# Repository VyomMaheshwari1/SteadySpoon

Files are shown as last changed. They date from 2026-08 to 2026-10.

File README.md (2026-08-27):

SteadySpoon

SteadySpoon is a prototype active-stabilization utensil that I'm building to experiment with reducing tremor-like hand motion.

The current setup uses an STM32G431 and an MPU6050. So far I've implemented I2C sensor communication, gyro calibration, tilt estimation, accelerometer/gyro fusion using a complementary filter, and PWM setup for the servos.

Right now I'm working on getting the first physical servo axis running.

\## Hardware

\- STM32 NUCLEO-G431KB

\- MPU6050 IMUs

\- KST DS215MG servos

\- External servo power supply

\## Current progress

\- STM32 + MPU6050 communication working

\- Real accelerometer and gyro readings working

\- Gyro bias calibration implemented

\- Complementary-filter angle estimation working

\- Servo PWM configured

\- Physical servo testing next

This is still a work in progress. CAD, test data, and stabilization results will be added as the prototype develops.

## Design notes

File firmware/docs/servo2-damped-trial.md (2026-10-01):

# Servo 2 damped controller trial

This revision is an unvalidated bench controller. It starts with Servo 2 held at 1500 us and Servo 1 centered. Physical stabilization performance has not been demonstrated. Do not mistake hold-center mode for active stabilization.

## Changes

- Correct gyro-rate projection to match the bounded accelerometer tilt definitions, including inverted sensor mounting.
- Retry MPU startup with bounded, open-drain I2C bus recovery and retained diagnostics.
- Use angle gain 2 us/degree, rate damping 0.08 us/(degree/s), and a 30 ms rate filter. Damping is limited to +/-20 us.
- Use integral gain 1 us/(degree*s), limited to 10 us/s and +/-150 us, with anti-windup.
- Limit commands to 1150–1850 us and nominal changes to 6 us per 10 ms control tick.
- Configure Servo 2 TIM3 for approximately 333 Hz PWM with 1 us resolution, for the KST DS215MG V8.0. Servo 1 timing is unchanged.

## Defaults and fault behavior

`servo2_hold_center_test` defaults to 1. Enabling feedback requires an explicit, supervised bench action. Automatic actuator testing is disabled.

`servo2_control_fault` latches until reset:

| Code | Trigger |
|---|---|
| 1 | Invalid, stale, nonfinite, or singular-coordinate sensor data |
| 2 | Active control interval outside the permitted timing window |
| 3 | Any carriage gyro axis reaches 450 degrees/second |
| 4 | Four rate reversals exceeding +/-100 degrees/second within 500 ms |

A fault freezes the last PWM command. It does **not** disconnect motor power. The oscillation guard can also trip on vigorous imposed motion; it is not a tremor classifier. Reset returns to hold-center mode.

Keep external servo power off when flashing. Refresh CubeMonitor variable addresses from the exact newly flashed ELF; rebuilding can move globals. Never use a stale zero-valued graph as evidence of stabilization. Include fault, inhibit, hold-center and sensor-health fields in subsequent recordings.

## Validation

ARM firmware build passed. Eleven isolated host tests exercise the actual controller functions: startup hold, command slew/integral limits, damping direction and decay, clipping/reversal latches, timing, stale data, anti-windup, timer wrap, duplicate samples and nonfinite input. Run `python firmware/tests/test_servo2_controller.py` with a host GCC compiler installed (`CC` can select it).

Replay of a prior unstable recording triggered the reversal guard and held the output. Replay verifies response to recorded inputs, not new closed-loop physical behavior. Hardware validation is still required. Known build warnings concern unused Servo 1 stabilization and the legacy automatic-response helper.

Reference: [KST DS215MG V8.0 specification](https://www.kst-servo-shop.de/media/9b/d5/38/1751020226/KST_0821_DS215MG_V8_Datenblatt_04_2025_de.pdf).

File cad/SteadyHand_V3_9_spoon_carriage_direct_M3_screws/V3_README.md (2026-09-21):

# SteadyHand V3.9 with direct screws in the spoon carriage

V3.9 keeps the corrected left-side servo wire opening and changes the spoon
carriage connection so it no longer requires heat-set inserts. The two former
4.6 mm insert pockets are now 2.6 mm pilot holes for ordinary M3 screws.

The handle correction was developed after inspecting a physical-fit
photo. The black rubber strain-relief was hitting the mounting wall before the
servo case could seat. The user confirmed that this interference is on the
left, so the lower-left mounting point is replaced by the wire-boot opening.
The servo lead is permanently attached, so clearance behind the servo was not
enough by itself: the lead also needs an open route through the mounting plate.

## V3.9 spoon-carriage change

- The red pitch-horn adapter retains 3.4 mm pass-through clearance holes.
- The yellow moving spoon carriage now has two 2.6 mm pilot holes.
- Use two M3 x 10 mm machine screws through the adapter. They form threads
  directly in the printed carriage bosses; no inserts or nuts are required.
- Do not drill the 2.6 mm carriage holes larger and do not overtighten them.

## Retained handle changes

- An 18 x 10 mm opening now occupies the lower-left servo mounting point.
- That opening overlaps the servo body opening and reaches the plate's side
  edge, allowing the black rubber boot and cable to enter without bending.
- The roll servo is fastened using the other three DS215 mounting holes. A 6 mm
  protected zone around each retained screw has been checked against the slot.
- Handle height is 34 mm: 2 mm more above and 2 mm more below the centerline.
- A dedicated 12 x 12 x 12 mm service envelope now clears the roll-servo rubber
  boot and the cable's first bend, not only the metal case.
- A small local side blister preserves wall thickness around that cable pocket.
- Front harness opening increased from 18 x 6 mm to 24 x 10 mm.
- Rear cable opening increased from 16 x 10 mm to 20 x 12 mm.
- Pitch-servo wire passage increased from 10 x 6 mm to 14 x 9 mm.

## Printable parts

1. `V3_9_DS215_fit_test_coupon.stl` - optional quick body/hole-pattern check.
2. `V3_9_handle_tray.stl` - includes the three-hole servo mount and left wire opening,
   Nucleo rails/zip-tie slots, and four handle-IMU standoffs.
3. `V3_9_handle_lid.stl` - flat four-screw lid with no tray interference.
4. `V3_9_integrated_outer_frame.stl` - roll yoke and pitch-servo bracket are one
   printed solid; there is no unexplained bracket-to-frame joint.
5. `V3_9_integrated_moving_carriage.stl` - pitch platform and spoon socket are one
   printed solid, now with two direct-screw M3 pilot holes.
6. `V3_9_pitch_horn_adapter.stl` - removable bridge from the purchased pitch
   horn to the moving carriage. This makes the center horn screw accessible.

## Verified interfaces

- KST DS215MG V8: 23 x 12 x 27.5 mm case, 32 x 12 mm ear envelope,
  four 2.5 mm holes on a 28 x 7 mm pattern, 25T/5 mm spline.
- KST-5034 one-arm horn: 28.4 mm overall, 7.5 mm wide, 1.8 mm arm,
  four 1.6 mm holes at 10, 13.5, 17, and 20.5 mm from the spline axis.
  The design uses the 10 and 17 mm holes at both powered joints.
- The round-looking 5 mm output is actually a 25-tooth spline. V3.9 shows
  visible conceptual teeth and the center retaining screw so the joint is not
  mistaken for a smooth pin. The tooth shape is reference-only because KST
  publishes 25T/5 mm but not the manufacturing tooth profile.
- Adafruit MPU6050 #3886: 25.4 x 17.78 mm nominal PCB outline in the Eagle
  source; four 2.5 mm holes on a 20.32 x 12.70 mm pattern.
- Neutral-position solid interference: zero for electronics, both complete
  servo references (including wire boots), the enlarged roll-wire bend
  envelope, frame, carriage, handle, and closed lid.
- Checked travel: pitch +/-50 degrees and roll +/-45 degrees.

## Required purchased hardware

- 2 x KST-5034 reinforced red plastic horn, 25T-5.
- 2 x horn-center screws supplied with the DS215 servos.
- 4 x M2 x 6-8 mm thread-forming screws for the horn-to-print connections.
- 2 x M3 x 10 mm machine screws for the pitch-adapter-to-spoon-carriage joint.
- 1 x M3 heat-set insert and one M3 pivot screw/washer for the passive pivot.

The red `REFERENCE_KST_5034...` files are purchased-part references only. Do
not print a plastic spline substitute. Print the DS215 coupon first, then
dry-fit both actual horns before printing or assembling the full mechanism.

## What attaches to what

The horn does **not** grip a smooth printed round shaft.

1. The horn's toothed center presses onto the servo's metal 25T/5 mm spline.
   The matching teeth transmit torque.
2. The small screw supplied with the servo goes through the horn center and
   threads into the servo shaft. It prevents the horn sliding off.
3. Two M2 screws through the horn's 10 and 17 mm arm holes connect it to the
   printed orange roll frame or the red pitch adapter.
4. The pitch adapter bolts to the yellow moving carriage with two M3 screws.
5. The round yellow feature on the opposite side is only the passive support
   pivot. It does not receive a servo horn and does not drive the carriage.

## Pitch-joint assembly order

1. Bolt the pitch servo to the outer frame.
2. Fasten the KST-5034 horn to `V3_9_pitch_horn_adapter` using the horn's 10 and
   17 mm holes and the adapter's two 2.2 mm holes.
3. Push the horn onto the yellow 25T servo spline and install KST's center screw
   through the adapter's large center access hole.
4. Place the moving carriage in the frame. Pass two M3 x 10 mm screws through
   the adapter's 3.4 mm holes and slowly drive them into the carriage's 2.6 mm
   pilot holes. Stop when snug; the printed plastic supplies the threads.
5. Install the M3 passive-pivot screw and washer from the left frame cheek.

For the roll joint, fasten the horn to the rear of the orange frame through its
10 and 17 mm holes, push it onto the roll-servo spline, then install the KST
center screw through the large center access opening.

## Roll-servo installation through the corrected mount

1. Put the black rubber strain-relief and attached lead into the 18 x 10 mm
   opening that replaces the lower-left screw position.
2. Slide the servo case into the rectangular opening while keeping the lead in
   the notch; do not clamp the wire under a mounting ear.
3. Install screws through the three remaining servo-ear mounting holes.
4. Route the lead through the internal bend pocket toward the controller.

If the corrected V3.8 handle and mechanism parts are already printed, keep
them. For this screw change, reprint only `V3_9_integrated_moving_carriage.stl`;
the existing V3.8 pitch-horn adapter remains compatible.

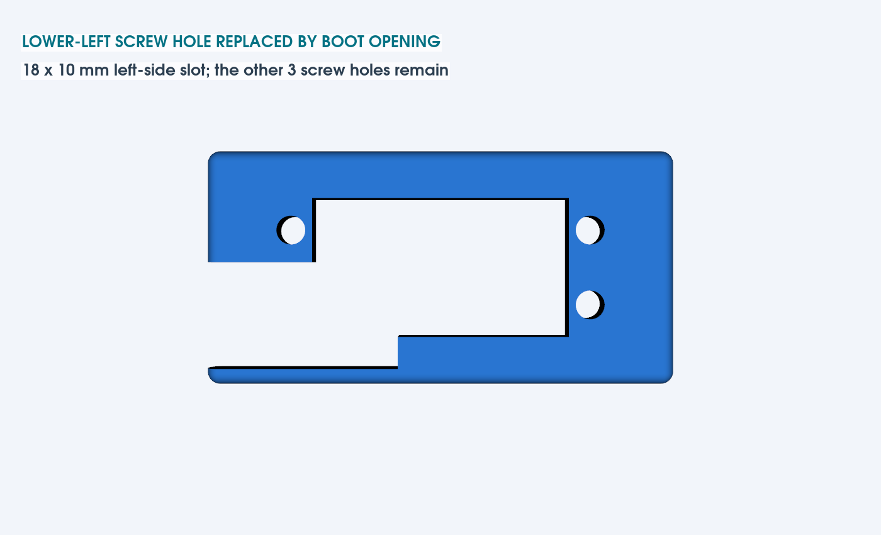
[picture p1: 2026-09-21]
cad/SteadyHand_V3_9_spoon_carriage_direct_M3_screws/PREVIEWS/V3_9_left_mount_replaced_by_wire_opening.png

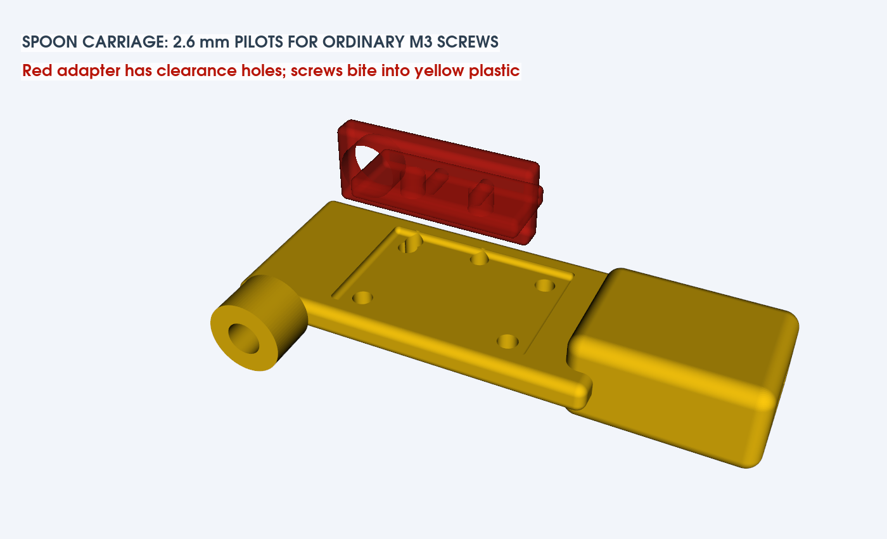
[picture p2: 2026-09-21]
cad/SteadyHand_V3_9_spoon_carriage_direct_M3_screws/PREVIEWS/V3_9_spoon_carriage_direct_M3_screws.png

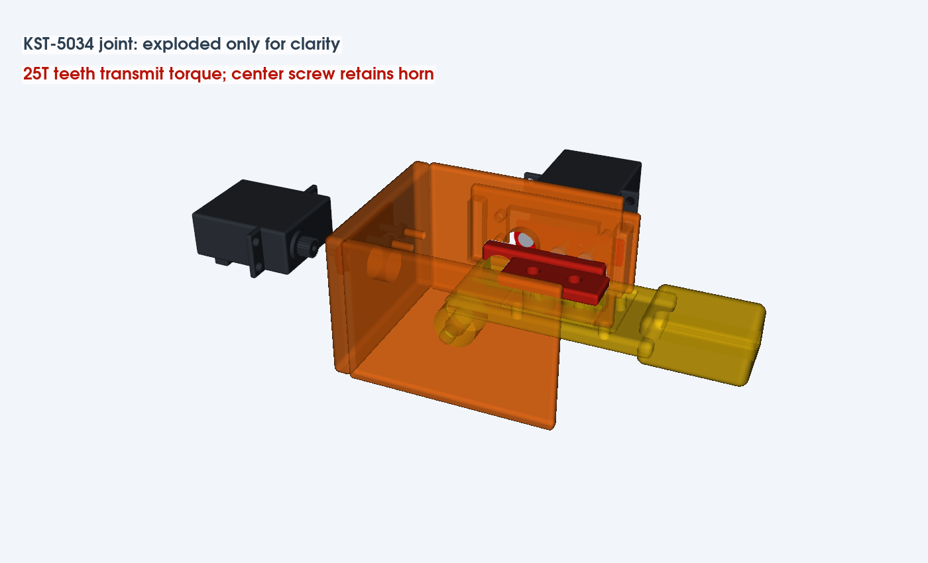
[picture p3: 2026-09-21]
cad/SteadyHand_V3_9_spoon_carriage_direct_M3_screws/PREVIEWS/V3_9_KST5034_horn_exploded.png

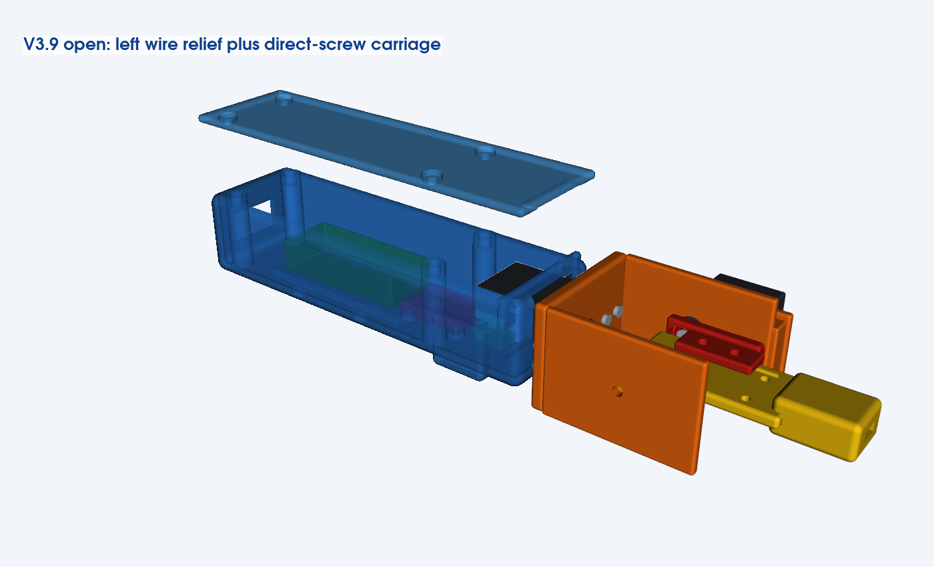
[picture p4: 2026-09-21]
cad/SteadyHand_V3_9_spoon_carriage_direct_M3_screws/PREVIEWS/V3_9_open_packaging.png

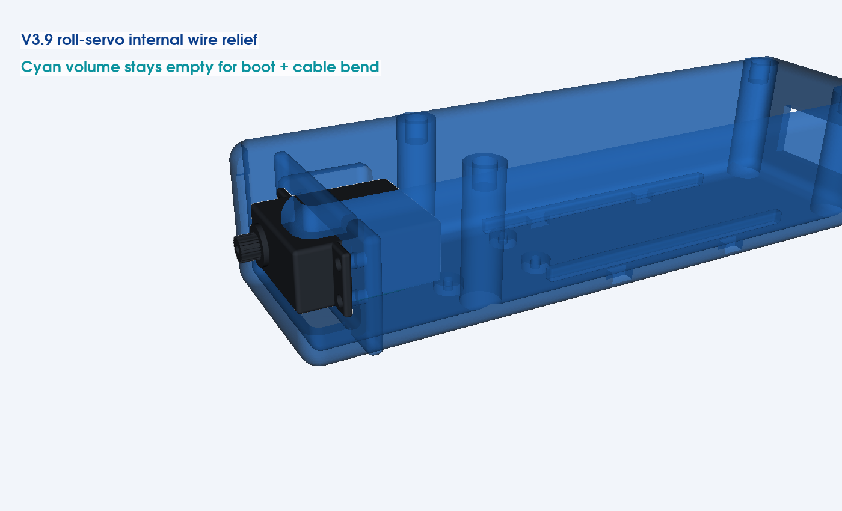
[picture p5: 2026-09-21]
cad/SteadyHand_V3_9_spoon_carriage_direct_M3_screws/PREVIEWS/V3_9_roll_servo_wire_clearance.png

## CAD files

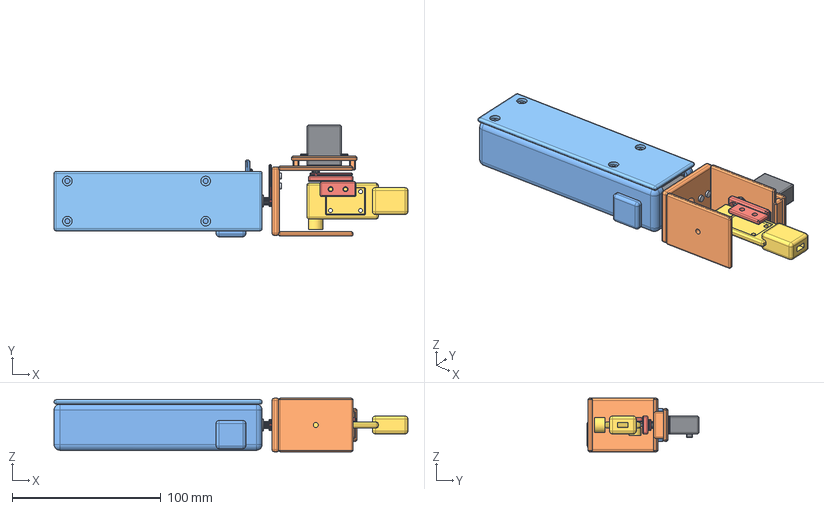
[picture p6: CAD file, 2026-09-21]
cad/SteadyHand_V3_9_spoon_carriage_direct_M3_screws/STEP_CAD/SteadyHand_V3_9_packaging_assembly.step
238.0 x 75.0 x 36.0 mm
handle_tray
handle_lid
integrated_outer_frame
integrated_moving_carriage
pitch_horn_adapter
DS215_roll_reference
DS215_pitch_reference
KST_5034_roll_horn
KST_5034_pitch_horn
roll_horn_fasteners
pitch_horn_fasteners
roll_servo_wire_service_envelope
NUCLEO_clearance_envelope
handle_IMU_envelope

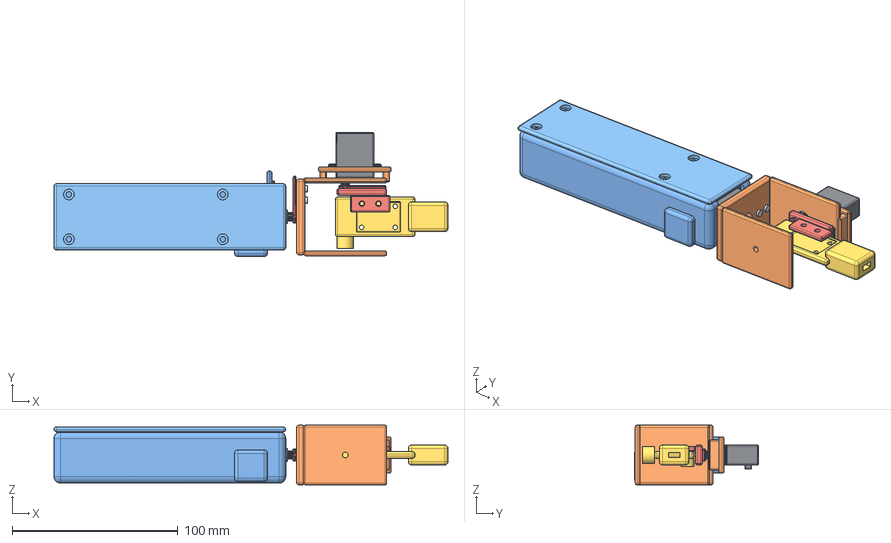
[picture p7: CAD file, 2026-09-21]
cad/SteadyHand_V3_9_spoon_carriage_direct_M3_screws/STEP_CAD/SteadyHand_V3_9_mechanical_audit_assembly.step
238.0 x 75.0 x 36.0 mm
handle_tray
handle_lid
integrated_outer_frame
integrated_moving_carriage
pitch_horn_adapter
DS215_roll_reference
DS215_pitch_reference
KST_5034_roll_horn
KST_5034_pitch_horn
roll_horn_fasteners
pitch_horn_fasteners
roll_servo_wire_service_envelope

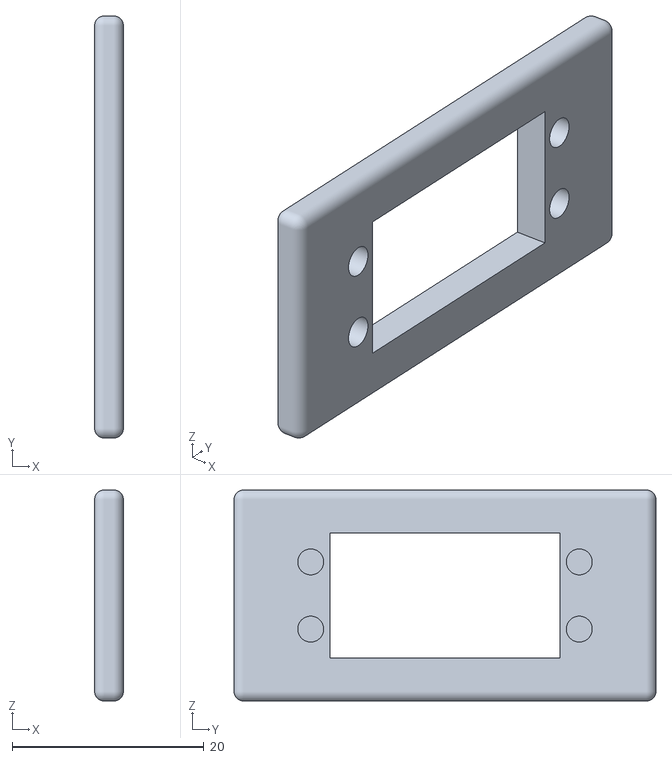
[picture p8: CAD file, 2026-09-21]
cad/SteadyHand_V3_9_spoon_carriage_direct_M3_screws/FULL_PRINT_SET_STL/V3_9_DS215_fit_test_coupon.stl
3.00 x 44.0 x 22.0

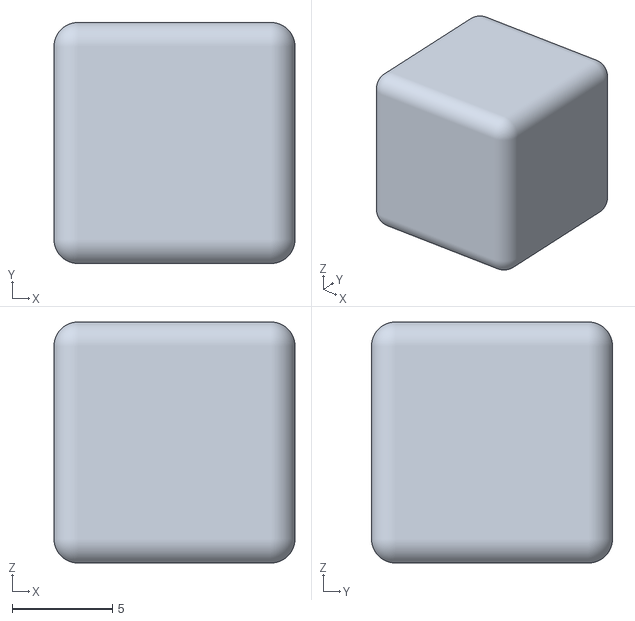
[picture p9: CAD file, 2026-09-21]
cad/SteadyHand_V3_9_spoon_carriage_direct_M3_screws/REFERENCE_DO_NOT_PRINT/REFERENCE_roll_servo_wire_service_envelope.stl
12.0 x 12.0 x 12.0

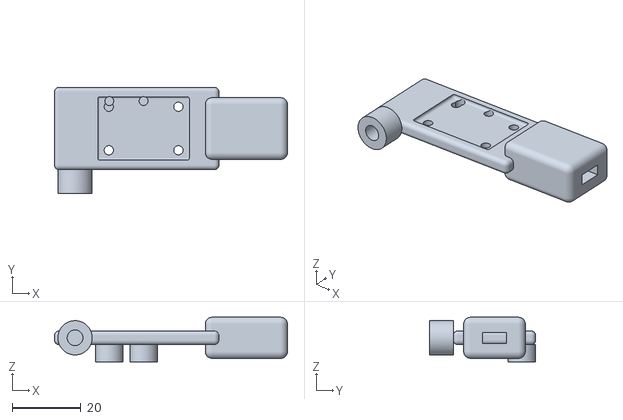
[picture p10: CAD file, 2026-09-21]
cad/SteadyHand_V3_9_spoon_carriage_direct_M3_screws/REPRINT_ONLY_THIS/V3_9_integrated_moving_carriage.stl
68.0 x 31.0 x 13.0

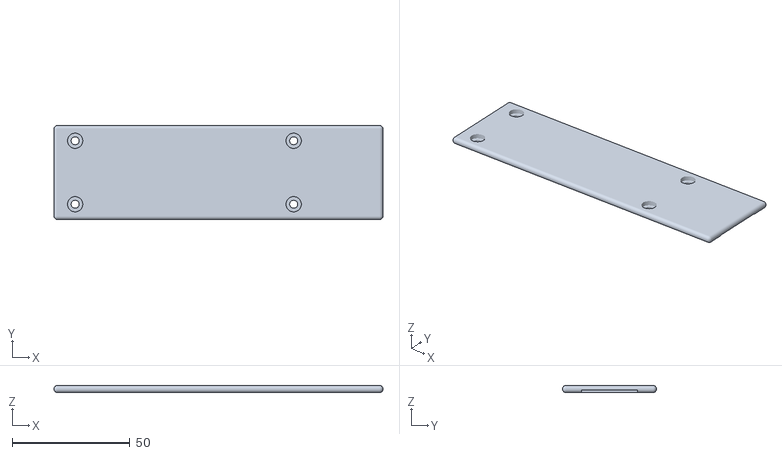
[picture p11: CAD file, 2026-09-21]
cad/SteadyHand_V3_9_spoon_carriage_direct_M3_screws/FULL_PRINT_SET_STL/V3_9_handle_lid.stl
140.0 x 40.0 x 3.00

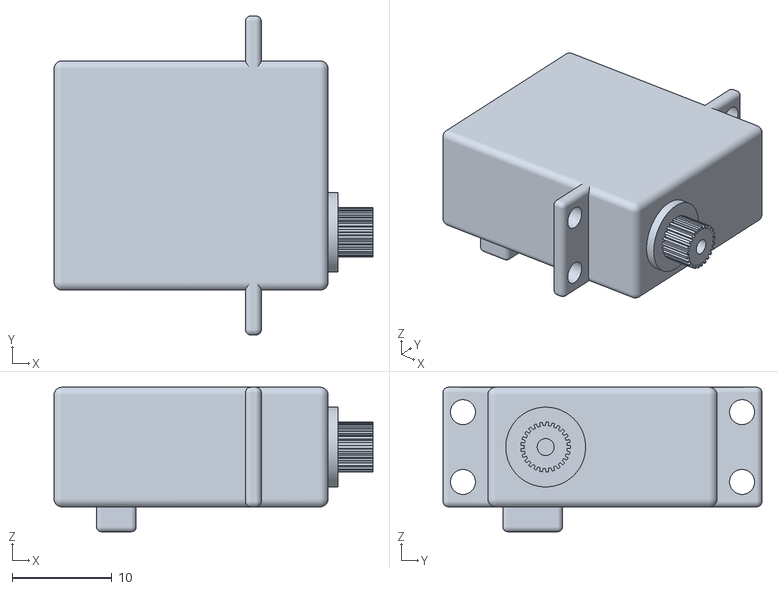
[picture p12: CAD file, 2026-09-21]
cad/SteadyHand_V3_9_spoon_carriage_direct_M3_screws/REFERENCE_DO_NOT_PRINT/REFERENCE_installed_roll_servo.stl
32.0 x 32.0 x 14.5

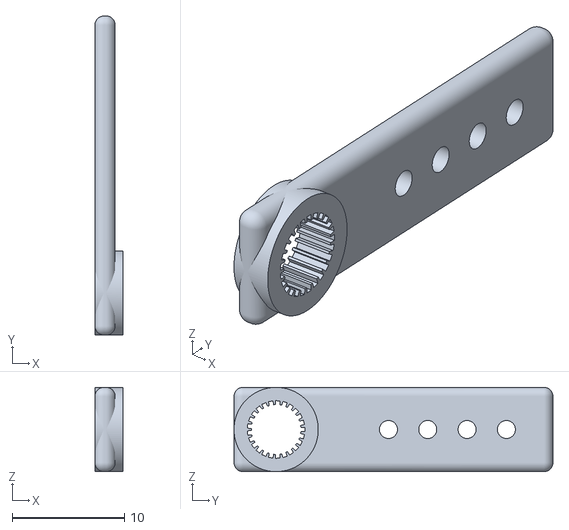
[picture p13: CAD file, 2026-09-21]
cad/SteadyHand_V3_9_spoon_carriage_direct_M3_screws/REFERENCE_DO_NOT_PRINT/REFERENCE_installed_roll_KST_5034_horn.stl
2.50 x 28.4 x 7.50

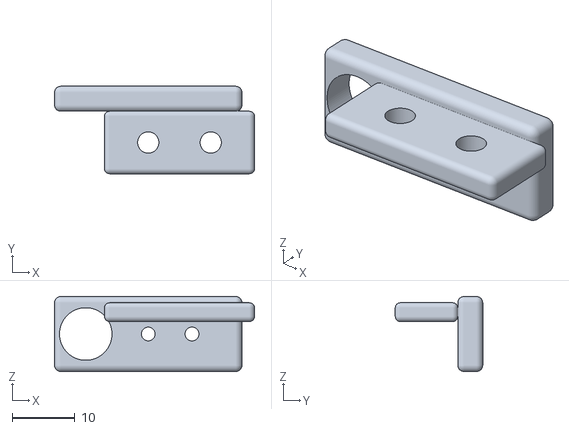
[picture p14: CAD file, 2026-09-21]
cad/SteadyHand_V3_9_spoon_carriage_direct_M3_screws/FULL_PRINT_SET_STL/V3_9_pitch_horn_adapter.stl
32.0 x 14.0 x 12.0

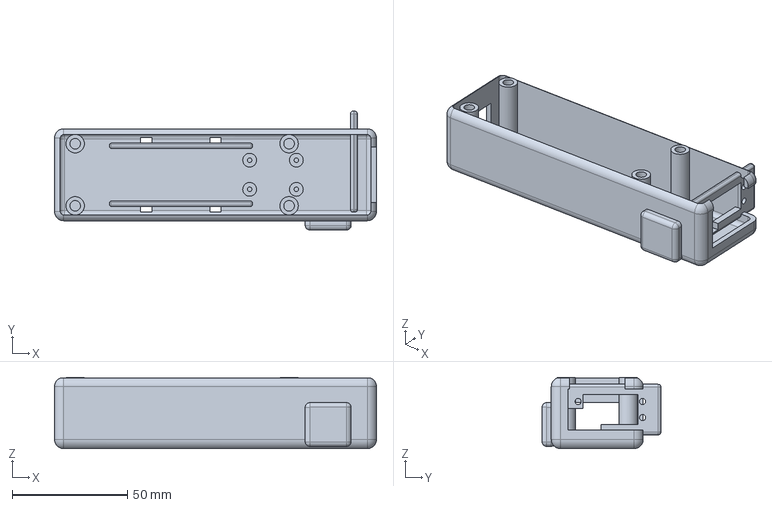
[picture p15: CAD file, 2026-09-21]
cad/SteadyHand_V3_9_spoon_carriage_direct_M3_screws/STEP_CAD/V3_9_handle_tray.step
140.0 x 51.7 x 31.0 mm

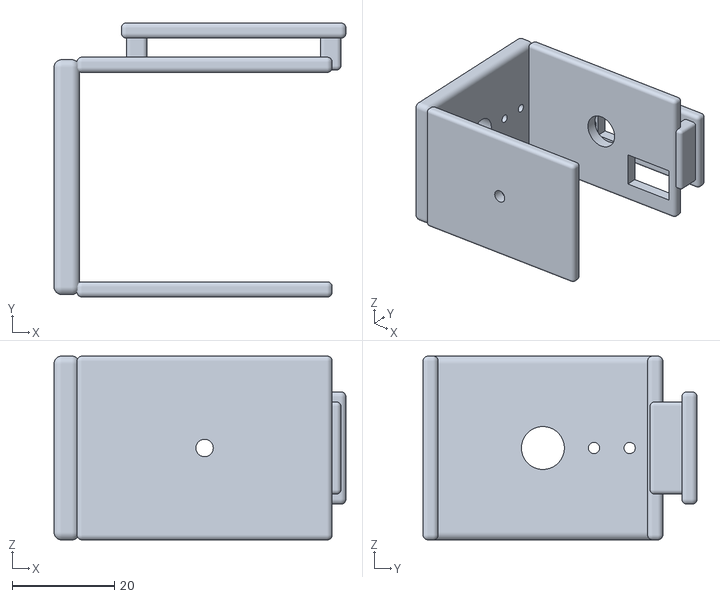
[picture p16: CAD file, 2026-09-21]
cad/SteadyHand_V3_9_spoon_carriage_direct_M3_screws/FULL_PRINT_SET_STL/V3_9_integrated_outer_frame.stl
57.2 x 53.7 x 36.0

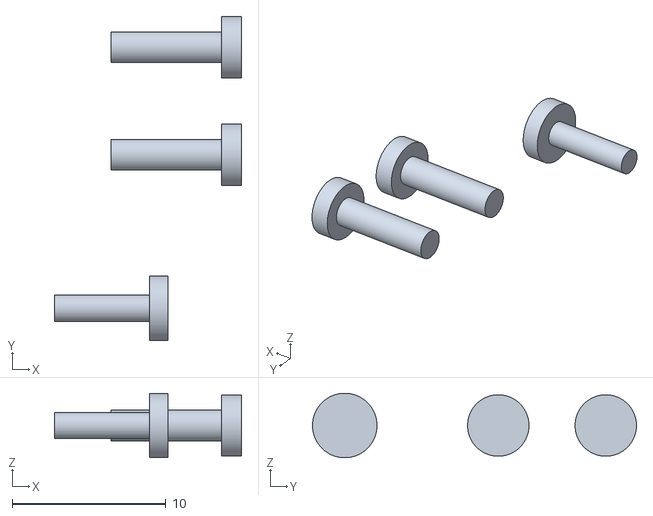
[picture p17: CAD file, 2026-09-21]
cad/SteadyHand_V3_9_spoon_carriage_direct_M3_screws/REFERENCE_DO_NOT_PRINT/REFERENCE_installed_roll_horn_fasteners.stl
12.2 x 21.1 x 4.20

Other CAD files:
cad/SteadyHand_V3_9_spoon_carriage_direct_M3_screws/STEP_CAD/V3_9_handle_lid.step
cad/SteadyHand_V3_9_spoon_carriage_direct_M3_screws/REFERENCE_DO_NOT_PRINT/REFERENCE_installed_pitch_servo.stl
cad/SteadyHand_V3_9_spoon_carriage_direct_M3_screws/STEP_CAD/V3_9_DS215_fit_test_coupon.step
cad/SteadyHand_V3_9_spoon_carriage_direct_M3_screws/FULL_PRINT_SET_STL/V3_9_handle_tray.stl
cad/SteadyHand_V3_9_spoon_carriage_direct_M3_screws/REFERENCE_DO_NOT_PRINT/REFERENCE_KST_5034_fasteners.stl
cad/SteadyHand_V3_9_spoon_carriage_direct_M3_screws/REFERENCE_DO_NOT_PRINT/REFERENCE_DS215MG_V8_verified_envelope.step
cad/SteadyHand_V3_9_spoon_carriage_direct_M3_screws/REFERENCE_DO_NOT_PRINT/REFERENCE_DS215MG_V8_verified_envelope.stl
cad/SteadyHand_V3_9_spoon_carriage_direct_M3_screws/REFERENCE_DO_NOT_PRINT/REFERENCE_KST_5034_horn.step
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

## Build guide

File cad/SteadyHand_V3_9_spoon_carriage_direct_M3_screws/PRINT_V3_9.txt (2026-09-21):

STEADYHAND V3.9 - DIRECT SCREWS FOR THE SPOON CARRIAGE

REPRINT ONLY THIS PART FOR THE SCREW-HOLE FIX:
  V3_9_integrated_moving_carriage.stl

The two spoon-carriage attachment holes are now 2.6 mm pilots. Use two ordinary
M3 x 10 mm machine screws. Pass each screw through the existing pitch-horn
adapter, then slowly screw it directly into the new carriage. Stop when snug.
No heat-set inserts or nuts are needed at this connection.

The existing V3.8 pitch-horn adapter, handle tray, lid, and outer frame remain
compatible. Do not reprint them solely for this change.

Do not print files beginning with REFERENCE.

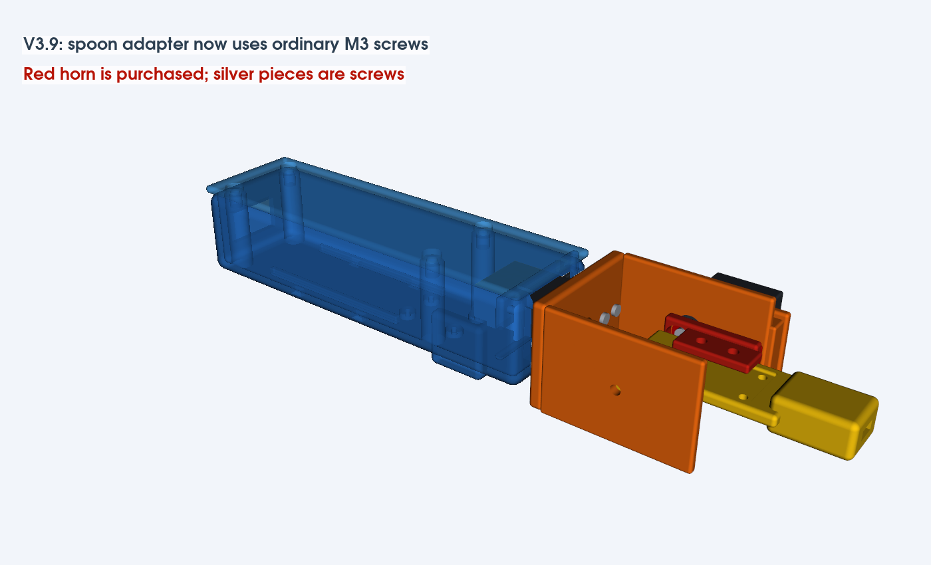
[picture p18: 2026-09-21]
cad/SteadyHand_V3_9_spoon_carriage_direct_M3_screws/PREVIEWS/V3_9_audited_assembly.png

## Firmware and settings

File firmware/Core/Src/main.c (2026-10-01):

#include "main.h"

#include "cmsis_os2.h"

#include <math.h>

/* ============================================================

 * MPU6050 DEFINITIONS

 * ============================================================ */

#define MPU6050_ADDR              (0x68 << 1)

#define MPU6050_WHO_AM_I          0x75

#define MPU6050_PWR_MGMT_1        0x6B

#define MPU6050_CONFIG            0x1A

#define MPU6050_GYRO_CONFIG       0x1B

#define MPU6050_ACCEL_CONFIG      0x1C

#define MPU6050_ACCEL_XOUT_H      0x3B

/*

 * DLPF_CFG = 3

 * Accelerometer bandwidth is about 44 Hz.

 * Gyroscope bandwidth is about 42 Hz.

 */

#define MPU6050_DLPF_CONFIG       0x03

/* ============================================================

 * SERVO 1

 * ============================================================ */

#define SERVO1_MIN_US             1000U

#define SERVO1_CENTER_US          1500U

#define SERVO1_MAX_US             2000U

#define SERVO1_GAIN               12.0f

#define SERVO1_DIRECTION          (-1.0f)

/* ============================================================

 * SERVO 2

 * ============================================================ */

#define SERVO2_MIN_US             1000U

#define SERVO2_CENTER_US          1500U

#define SERVO2_MAX_US             2000U

#define SERVO2_RESPONSE_TEST      0U /* Normal stabilization; identification test disabled. */

#define SERVO2_GAIN               2.0f /* Conservative unvalidated damped-controller bench setting. */
#define SERVO2_MAX_SAMPLE_AGE_MS  20U
#define SERVO2_KI_US_PER_DEG_S    1.0f
#define SERVO2_I_RATE_US_PER_S   10.0f
#define SERVO2_I_LIMIT_US        150.0f
#define SERVO2_SAFE_MIN_US        1150.0f
#define SERVO2_SAFE_MAX_US        1850.0f

/*

 * If Servo2 compensates in the wrong direction,

 * later change this between -1.0f and +1.0f.

 */

#define SERVO2_DIRECTION          (-1.0f)

#define ANGLE_DEADBAND_DEG        0.3f

/* Maximum PWM movement allowed during one 10 ms control cycle. */

#define MAX_SERVO_STEP_US         30U

/* ============================================================

 * STM32 PERIPHERAL HANDLES

 * ============================================================ */

I2C_HandleTypeDef hi2c1;

I2C_HandleTypeDef hi2c2;

TIM_HandleTypeDef htim3;

TIM_HandleTypeDef htim4;

/* ============================================================

 * MPU6050 STRUCTURE

 * ============================================================ */

typedef struct

{

    I2C_HandleTypeDef *i2c;

    uint8_t who_am_i;

    uint8_t ok;

    uint8_t filter_initialized;

    uint8_t sensor_data[14];

    int16_t accel_x_raw;

    int16_t accel_y_raw;

    int16_t accel_z_raw;

    int16_t gyro_x_raw;

    int16_t gyro_y_raw;

    int16_t gyro_z_raw;

    float accel_x_g;

    float accel_y_g;

    float accel_z_g;

    float gyro_x_dps;

    float gyro_y_dps;

    float gyro_z_dps;

    float gyro_x_bias;

    float gyro_y_bias;

    float gyro_z_bias;

    float pitch_accel_deg;

    float roll_accel_deg;

    float pitch_filtered_deg;

    float roll_filtered_deg;

    float pitch_reference_deg;

    float roll_reference_deg;

    uint32_t last_update_ms;
    HAL_StatusTypeDef read_status;
    uint32_t read_count;
    uint32_t read_failures;
    uint16_t gyro_samples;
    uint16_t reference_samples;

} MPU6050_t;

/* ============================================================

 * MPU OBJECTS

 * ============================================================ */

MPU6050_t mpu1 = {0};

MPU6050_t mpu2 = {0};

/* ============================================================

 * SERVO / DEBUG VARIABLES

 * ============================================================ */

volatile uint16_t servo1_pulse_us =

    SERVO1_CENTER_US;

volatile uint16_t servo2_pulse_us =

    SERVO2_CENTER_US;

volatile float servo1_relative_angle = 0.0f;

volatile float servo1_error = 0.0f;

volatile float servo1_correction = 0.0f;

volatile float servo2_relative_angle = 0.0f;

volatile float servo2_error = 0.0f;

volatile float servo2_correction = 0.0f;
volatile float servo2_command_us_f = 1500.0f;
/* Diagnostic baseline: 1 holds Servo 2 at center; 0 enables stabilization.
 * This build starts with feedback disabled; explicit bench arming is required. */
volatile uint32_t servo2_hold_center_test = 1U; /* Feedback disabled at boot after observed oscillation. */
/* Faults latch until reboot: 1 sensor invalid, 2 timing, 3 gyro clipping,
 * 4 repeated high-rate reversals. Fault holds last PWM, not a motor power cut. */
volatile uint32_t servo2_control_fault;
volatile float servo2_roll_rate_dps, servo2_d_term_us;

volatile float servo2_integral_us = 0.0f; /* Signed PWM offset, retained near zero error. */
volatile float servo2_p_term_us = 0.0f;
volatile float servo2_control_dt_s = 0.0f;
volatile float servo2_measured_roll_deg = 0.0f;
volatile float servo2_reference_roll_deg = 0.0f;
volatile float mpu2_accel_roll_deg, mpu2_gyro_x_dps, mpu2_pitch_deg;
/* Handle measurements only: do not feed MPU1 into Servo 2 control. */
volatile float mpu1_relative_roll_deg, mpu1_relative_pitch_deg;
volatile float mpu1_gyro_x_dps, mpu1_gyro_y_dps, mpu1_gyro_z_dps;
volatile uint32_t mpu1_valid, mpu1_sample_age_ms, mpu1_read_count;
volatile uint32_t mpu1_read_failures, mpu1_who_am_i;
volatile HAL_StatusTypeDef mpu1_read_status;
volatile uint32_t mpu2_read_count, mpu2_read_failures, mpu2_sample_age_ms;
volatile uint32_t mpu2_i2c_error, mpu2_who_am_i, mpu2_ok;
volatile uint32_t mpu2_gyro_samples, mpu2_reference_samples;
volatile HAL_StatusTypeDef mpu2_read_status;
volatile uint32_t servo2_inhibit = 1U, servo2_saturated, servo2_ccr3;
volatile uint32_t imu_step_ms, control_period_ms;

volatile HAL_StatusTypeDef servo1_pwm_status;

volatile HAL_StatusTypeDef servo2_pwm_status;

/* Startup-only diagnostics. Stage: 1 identity, 2 wake, 3 DLPF,
 * 4 gyro range, 5 accel range, 6 initialized. A successful retry preserves
 * last_failed_* so a transient failure is not hidden by later runtime reads.
 * HAL status: 0 OK, 1 ERROR, 2 BUSY, 3 TIMEOUT. Wrong identity can have status 0. */
typedef struct {
    uint32_t attempts;
    uint32_t stage;
    HAL_StatusTypeDef status;
    uint32_t i2c_error;
    uint32_t last_failed_stage;
    HAL_StatusTypeDef last_failed_status;
    uint32_t last_failed_i2c_error;
    uint32_t last_failed_who_am_i;
} MPU6050_InitDebug_t;
volatile MPU6050_InitDebug_t mpu1_startup, mpu2_startup;
volatile uint32_t mpu1_gyro_samples, mpu1_reference_samples;

/* Response test: 0 countdown, 1 baseline, 2 +50 us, 3 center,
 * 4 -50 us, 5 center, 6 complete, 7 aborted. Does not rearm until reset.
 * Fault: 1 invalid sensors, 2 handle moved >3 deg, 3 carriage moved >20 deg,
 * 4 control gap >50 ms, 5 explicit center-test override. */
volatile uint32_t servo2_test_state, servo2_test_fault, servo2_test_elapsed_ms;



/*

 * These let us verify FreeRTOS is actually running.

 *

 * imu_task_count should increase about twice

 * as fast as control_task_count.

 */

volatile uint32_t imu_task_count = 0;

volatile uint32_t control_task_count = 0;

/* ============================================================

 * FUNCTION PROTOTYPES

 * ============================================================ */

void SystemClock_Config(void);

static void MX_GPIO_Init(void);

static void MX_I2C1_Init(void);

static void MX_I2C2_Init(void);

static void MX_TIM3_Init(void);

static void MX_TIM4_Init(void);

/*

 * Generated/configured by the MSP file.

 */

void HAL_TIM_MspPostInit(

    TIM_HandleTypeDef *htim

);

/*

 * Implemented in app_freertos.c.

 */

extern void MX_FREERTOS_Init(void);

/* MPU functions */

static void MPU6050_Init(

    MPU6050_t *mpu

);

static void MPU6050_CalibrateGyro(

    MPU6050_t *mpu

);

static uint8_t MPU6050_Update(

    MPU6050_t *mpu

);

static void MPU6050_CalibrateReference(

    MPU6050_t *mpu

);

/* Servo functions */

static void Servo1_SetPulse(

    uint16_t pulse_us

);

static void Servo2_SetPulse(

    uint16_t pulse_us

);

static uint16_t Servo_LimitStep(

    uint16_t current,

    uint16_t target

);

static void Servo1_Stabilization_Update(void);

static void Servo2_Stabilization_Update(void);

/*

 * These are called by app_freertos.c.

 */

void App_IMU_TaskStep(void);

void App_Control_TaskStep(void);

/* ============================================================

 * SERVO SLEW RATE LIMITER

 * Prevents sudden PWM jumps between control cycles.

 * ============================================================ */

static uint16_t Servo_LimitStep(

    uint16_t current,

    uint16_t target

)

{

    if (target > current)

    {

        uint16_t difference = target - current;

        if (difference > MAX_SERVO_STEP_US)

        {

            return current + MAX_SERVO_STEP_US;

        }

    }

    else if (target < current)

    {

        uint16_t difference = current - target;

        if (difference > MAX_SERVO_STEP_US)

        {

            return current - MAX_SERVO_STEP_US;

        }

    }

    return target;

}

/* ============================================================

 * SERVO 1 PWM

 * ============================================================ */

static void Servo1_SetPulse(

    uint16_t pulse_us

)

{

    if (pulse_us < SERVO1_MIN_US)

    {

        pulse_us = SERVO1_MIN_US;

    }

    if (pulse_us > SERVO1_MAX_US)

    {

        pulse_us = SERVO1_MAX_US;

    }

    servo1_pulse_us =

        pulse_us;

    __HAL_TIM_SET_COMPARE(

        &htim4,

        TIM_CHANNEL_1,

        pulse_us

    );

}

/* ============================================================

 * SERVO 2 PWM

 * ============================================================ */

static void Servo2_SetPulse(

    uint16_t pulse_us

)

{

    if (pulse_us < SERVO2_MIN_US)

    {

        pulse_us = SERVO2_MIN_US;

    }

    if (pulse_us > SERVO2_MAX_US)

    {

        pulse_us = SERVO2_MAX_US;

    }

    servo2_pulse_us =

        pulse_us;

    __HAL_TIM_SET_COMPARE(

        &htim3,

        TIM_CHANNEL_3,

        pulse_us

    );

}

/* ============================================================

 * SERVO 1 STABILIZATION

 *

 * MPU1 pitch -> Servo1

 * ============================================================ */

static void Servo1_Stabilization_Update(void)

{

    if (

        !mpu1.ok ||

        !mpu1.filter_initialized

    )

    {

        return;

    }

    servo1_relative_angle =

        mpu1.pitch_filtered_deg -

        mpu1.pitch_reference_deg;

    servo1_error =

        servo1_relative_angle;

    if (

        fabsf(servo1_error) <

        ANGLE_DEADBAND_DEG

    )

    {

        servo1_error = 0.0f;

    }

    servo1_correction =

        servo1_error *

        SERVO1_GAIN;

    float command =

        (float)SERVO1_CENTER_US +

        (

            SERVO1_DIRECTION *

            servo1_correction

        );

    int32_t servo_command =

        (int32_t)command;

    if (

        servo_command <

        (int32_t)SERVO1_MIN_US

    )

    {

        servo_command =

            SERVO1_MIN_US;

    }

    if (

        servo_command >

        (int32_t)SERVO1_MAX_US

    )

    {

        servo_command =

            SERVO1_MAX_US;

    }

    uint16_t servo_target =

        (uint16_t)servo_command;

    uint16_t servo_limited =

        Servo_LimitStep(

            servo1_pulse_us,

            servo_target

        );

    Servo1_SetPulse(

        servo_limited

    );

}

/* ============================================================

 * SERVO 2 STABILIZATION

 *

 * MPU2 roll -> Servo2

 * ============================================================ */
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
int main(void)

{

    /*

     * Initialize STM32 HAL.

     *

     * HAL timing now uses TIM6 because

     * FreeRTOS uses SysTick.

     */

    HAL_Init();

    /*

     * Configure 16 MHz HSI clock.

     */

    SystemClock_Config();

    /*

     * Initialize GPIO.

     */

    MX_GPIO_Init();

    /*

     * Initialize both I2C peripherals.

     */

    MX_I2C1_Init();

    MX_I2C2_Init();

    /*

     * Initialize both servo timers.

     */

    MX_TIM3_Init();

    MX_TIM4_Init();

    /*

     * Attach MPU1 to I2C1.

     */

    mpu1.i2c =

        &hi2c1;

    /*

     * Attach MPU2 to I2C2.

     */

    mpu2.i2c =

        &hi2c2;

    /*

     * Initialize sensors.

     */

    MPU6050_Init(

        &mpu1

    );

    MPU6050_Init(

        &mpu2

    );

    /*

     * KEEP BOTH MPUs STILL HERE.

     *

     * This takes roughly two seconds total.

     */

    MPU6050_CalibrateGyro(

        &mpu1

    );

    MPU6050_CalibrateGyro(

        &mpu2

    );

    /*

     * Start Servo1 PWM.

     */

    servo1_pwm_status =

        HAL_TIM_PWM_Start(

            &htim4,

            TIM_CHANNEL_1

        );

    Servo1_SetPulse(

        SERVO1_CENTER_US

    );

    /*

     * Start Servo2 PWM.

     */

    servo2_pwm_status =

        HAL_TIM_PWM_Start(

            &htim3,

            TIM_CHANNEL_3

        );

    Servo2_SetPulse(

        SERVO2_CENTER_US

    );

    /*

     * Give everything time to settle.

     */

    HAL_Delay(

        1000

    );

    /*

     * KEEP SPOON STILL HERE.

     *

     * Current position becomes zero.

     */

    MPU6050_CalibrateReference(

        &mpu1

    );

    MPU6050_CalibrateReference(

        &mpu2

    );

    /*

     * Initialize FreeRTOS.

     */

    osKernelInitialize();

    /*

     * Create imuTask and controlTask.

     */

    MX_FREERTOS_Init();

    /*

     * Start FreeRTOS scheduler.

     */

    osKernelStart();

    /*

     * Normally we never reach this point.

     */

    while (1)

    {

    }

}

/* ============================================================

 * SYSTEM CLOCK

 *

 * HSI = 16 MHz

 * ============================================================ */

void SystemClock_Config(void)

{

    RCC_OscInitTypeDef

        RCC_OscInitStruct =

        {0};

    RCC_ClkInitTypeDef

        RCC_ClkInitStruct =

        {0};

    HAL_PWREx_ControlVoltageScaling(

        PWR_REGULATOR_VOLTAGE_SCALE1

    );

    RCC_OscInitStruct.OscillatorType =

        RCC_OSCILLATORTYPE_HSI;

    RCC_OscInitStruct.HSIState =

        RCC_HSI_ON;

    RCC_OscInitStruct.HSICalibrationValue =

        RCC_HSICALIBRATION_DEFAULT;

    RCC_OscInitStruct.PLL.PLLState =

        RCC_PLL_NONE;

    if (

        HAL_RCC_OscConfig(

            &RCC_OscInitStruct

        )

        !=

        HAL_OK

    )

    {

        Error_Handler();

    }

    RCC_ClkInitStruct.ClockType =

        RCC_CLOCKTYPE_HCLK |

        RCC_CLOCKTYPE_SYSCLK |

        RCC_CLOCKTYPE_PCLK1 |

        RCC_CLOCKTYPE_PCLK2;

    RCC_ClkInitStruct.SYSCLKSource =

        RCC_SYSCLKSOURCE_HSI;

    RCC_ClkInitStruct.AHBCLKDivider =

        RCC_SYSCLK_DIV1;

    RCC_ClkInitStruct.APB1CLKDivider =

        RCC_HCLK_DIV1;

    RCC_ClkInitStruct.APB2CLKDivider =

        RCC_HCLK_DIV1;

    if (

        HAL_RCC_ClockConfig(

            &RCC_ClkInitStruct,

            FLASH_LATENCY_0

        )

        !=

        HAL_OK

    )

    {

        Error_Handler();

    }

}

/* ============================================================

 * I2C1

 *

 * MPU1

 *

 * SCL = PA15

 * SDA = PB7

 * ============================================================ */

static void MX_I2C1_Init(void)

{

    hi2c1.Instance =

        I2C1;

    hi2c1.Init.Timing =

        0x00503D58;

    hi2c1.Init.OwnAddress1 =

        0;

    hi2c1.Init.AddressingMode =

        I2C_ADDRESSINGMODE_7BIT;

    hi2c1.Init.DualAddressMode =

        I2C_DUALADDRESS_DISABLE;

    hi2c1.Init.OwnAddress2 =

        0;

    hi2c1.Init.OwnAddress2Masks =

        I2C_OA2_NOMASK;

    hi2c1.Init.GeneralCallMode =

        I2C_GENERALCALL_DISABLE;

    hi2c1.Init.NoStretchMode =

        I2C_NOSTRETCH_DISABLE;

    if (

        HAL_I2C_Init(

            &hi2c1

        )

        !=

        HAL_OK

    )

    {

        Error_Handler();

    }

    if (

        HAL_I2CEx_ConfigAnalogFilter(

            &hi2c1,

            I2C_ANALOGFILTER_ENABLE

        )

        !=

        HAL_OK

    )

    {

        Error_Handler();

    }

    if (

        HAL_I2CEx_ConfigDigitalFilter(

            &hi2c1,

            0

        )

        !=

        HAL_OK

    )

    {

        Error_Handler();

    }

}

/* ============================================================

 * I2C2

 *

 * MPU2

 *

 * SDA = PA8

 * SCL = PA9

 * ============================================================ */

static void MX_I2C2_Init(void)

{

    hi2c2.Instance =

        I2C2;

    hi2c2.Init.Timing =

        0x00503D58;

    hi2c2.Init.OwnAddress1 =

        0;

    hi2c2.Init.AddressingMode =

        I2C_ADDRESSINGMODE_7BIT;

    hi2c2.Init.DualAddressMode =

        I2C_DUALADDRESS_DISABLE;

    hi2c2.Init.OwnAddress2 =

        0;

    hi2c2.Init.OwnAddress2Masks =

        I2C_OA2_NOMASK;

    hi2c2.Init.GeneralCallMode =

        I2C_GENERALCALL_DISABLE;

    hi2c2.Init.NoStretchMode =

        I2C_NOSTRETCH_DISABLE;

    if (

        HAL_I2C_Init(

            &hi2c2

        )

        !=

        HAL_OK

    )

    {

        Error_Handler();

    }

    if (

        HAL_I2CEx_ConfigAnalogFilter(

            &hi2c2,

            I2C_ANALOGFILTER_ENABLE

        )

        !=

        HAL_OK

    )

    {

        Error_Handler();

    }

    if (

        HAL_I2CEx_ConfigDigitalFilter(

            &hi2c2,

            0

        )

        !=

        HAL_OK

    )

    {

        Error_Handler();

    }

}

/* ============================================================

 * TIM3

 *

 * SERVO2

 *

 * PB0 = TIM3 CH3

 *

 * 16 MHz / 16 = 1 MHz

 * 1 timer count = 1 microsecond

 *

 * period = 20000 us = 50 Hz

 * ============================================================ */

static void MX_TIM3_Init(void)

{

    TIM_ClockConfigTypeDef

        sClockSourceConfig =

        {0};

    TIM_MasterConfigTypeDef

        sMasterConfig =

        {0};

    TIM_OC_InitTypeDef

        sConfigOC =

        {0};

    htim3.Instance =

        TIM3;

    htim3.Init.Prescaler =

        15;

    htim3.Init.CounterMode =

        TIM_COUNTERMODE_UP;

    htim3.Init.Period =

        3002; /* 1 MHz / 3003 = 333 Hz; DS215MG V8.0 only. */

    htim3.Init.ClockDivision =

        TIM_CLOCKDIVISION_DIV1;

    htim3.Init.AutoReloadPreload =

        TIM_AUTORELOAD_PRELOAD_DISABLE;

    if (

        HAL_TIM_Base_Init(

            &htim3

        )

        !=

        HAL_OK

    )

    {

        Error_Handler();

    }

    sClockSourceConfig.ClockSource =

        TIM_CLOCKSOURCE_INTERNAL;

    if (

        HAL_TIM_ConfigClockSource(

            &htim3,

            &sClockSourceConfig

        )

        !=

        HAL_OK

    )

    {

        Error_Handler();

    }

    if (

        HAL_TIM_PWM_Init(

            &htim3

        )

        !=

        HAL_OK

    )

    {

        Error_Handler();

    }

    sMasterConfig.MasterOutputTrigger =

        TIM_TRGO_RESET;

    sMasterConfig.MasterSlaveMode =

        TIM_MASTERSLAVEMODE_DISABLE;

    if (

        HAL_TIMEx_MasterConfigSynchronization(

            &htim3,

            &sMasterConfig

        )

        !=

        HAL_OK

    )

    {

        Error_Handler();

    }

    sConfigOC.OCMode =

        TIM_OCMODE_PWM1;

    sConfigOC.Pulse =

        SERVO2_CENTER_US;

    sConfigOC.OCPolarity =

        TIM_OCPOLARITY_HIGH;

    sConfigOC.OCFastMode =

        TIM_OCFAST_DISABLE;

    if (

        HAL_TIM_PWM_ConfigChannel(

            &htim3,

            &sConfigOC,

            TIM_CHANNEL_3

        )

        !=

        HAL_OK

    )

    {

        Error_Handler();

    }

    HAL_TIM_MspPostInit(

        &htim3

    );

}

/* ============================================================

 * TIM4

 *

 * SERVO1

 *

 * PB6 = TIM4 CH1

 * ============================================================ */

static void MX_TIM4_Init(void)
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

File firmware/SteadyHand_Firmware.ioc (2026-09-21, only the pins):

Mcu.UserName=STM32G431KBTx
PA15.Signal=I2C1_SCL
PA8.Signal=I2C2_SDA
PA9.Signal=I2C2_SCL
PB0.Signal=S_TIM3_CH3
PB6.Signal=S_TIM4_CH1
PB7.Signal=I2C1_SDA
PB8-BOOT0.Signal=GPIO_Output

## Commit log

2026-08-27 STM32 sensor bring-up and motion estimation with IMU
2026-09-21 Add dual MPU6050 and dual servo stabilization
2026-09-21 Add latest SteadySpoon CAD files
    [REFERENCE_DS215MG_V8_verified_envelope.step, REFERENCE_DS215MG_V8_verified_envelope.stl, REFERENCE_KST_5034_fasteners.stl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]
2026-09-21 Add FreeRTOS scheduling for dual MPU and servo control
2026-09-26 added servo 2 fixes
    [main.c]
2026-09-26 Checkpoint before Servo2 debugging
2026-09-27 added fixed tuning and pi
    [main.c]
2026-10-01 Add guarded Servo 2 damping trial and correct IMU tilt rates
    [main.c, test_servo2_controller.py]
2026-10-17 Use bounded handle feedforward for Servo 2 and document measured trial
